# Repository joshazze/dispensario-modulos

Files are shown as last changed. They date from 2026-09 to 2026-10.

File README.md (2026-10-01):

# Dispensário eletrônico · módulos em MDF

Chassi do protótipo do dispensário eletrônico da disciplina de Projeto de Sistemas Embarcados. São dois módulos de MDF cortado a laser, e cada painel é um sanduíche de duas lâminas de 3 mm. Nada aqui foi desenhado à mão: as medidas moram em [`specs/modulos.json`](specs/modulos.json), o [`gerador.py`](gerador.py) desenha, confere e exporta.

A linguagem construtiva (enforca-gato, dedos, camada dupla, gota de parede, pílula) está documentada no repositório irmão, **[dispensario-design-system](https://github.com/joshazze/dispensario-design-system)**.

Componentes comprados (LCD, teclado, parafusos, prensa-cabo), a fonte de cada medida usada no desenho e os arquivos de cada um estão em **[docs/componentes.md](docs/componentes.md)**.

<p align="center">Vista isométrica do armário e do módulo biométrico</p>

## Estado

| módulo | medida externa (L x A x P) | peças | situação |
|---|---|---|---|
| Biométrico, código `B` | 250 x 1000 x 250 mm | 19 | **pronto para a máquina**, em 4 cargas de até 1000 x 1000 mm |
| Armário, código `A` | 1260 x 1500 x 350 mm | 20 | **rascunho**: 12 painéis são maiores que a mesa |

Já cortadas em 03/09/2026: `BP1`, `BP2`, `BP3`, `BSP`, `B3E`, `B5E`, `BTR` e `BTF`. A `BSP` foi cortada antes de ganhar os vãos do LCD e do teclado; eles saem num arquivo à parte, `interface-vaos.dxf`, para cortar na peça que já existe.

Máquina de referência: eCNC L-1210, mesa de 1150 x 1000 mm. Cada carga usa no máximo 1000 mm de largura, folga entre peças incluída, e os 150 mm que sobram ficam de margem.

## Arquivos de corte

```
cortes/
├── biometrico/
│   ├── modulo-biometrico-bloco1.dxf   ← carga 1 da máquina (e .pdf, .svg)
│   ├── modulo-biometrico-bloco2.dxf
│   ├── modulo-biometrico-bloco3.dxf
│   ├── modulo-biometrico-bloco4.dxf
│   ├── modulo-biometrico.dxf          ← as 19 peças numa prancha só
│   └── interface-vaos.dxf             ← só os vãos do LCD e do teclado, sem contorno
└── armario/
    └── modulo-armario.dxf             ← prancha de conferência, ainda não cortável
```

Para a máquina vai o `.dxf`. O `.pdf` tem a mesma prancha em escala 1:1 para conferir na tela ou imprimir, e o `.svg` é o mesmo desenho em vetor.

Todo DXF sai no perfil que o técnico do laboratório usa: AutoCAD 2018 (AC1032), unidade em milímetro, camada `CORTE` na cor 1 (vermelho), contornos em `LWPOLYLINE` e `CIRCLE`, sem moldura da mesa e com o ponto mais baixo à esquerda em (0, 0). Os furos e recortes vêm antes do contorno externo de cada peça: cortado o perímetro, a peça se solta e o furo sairia torto.

### As quatro cargas do biométrico

| carga | área ocupada | peças |
|---|---|---|
| 1 | 1000 x 944 mm | `B1I`, `B1E`, `B2I`, `BPM` |
| 2 | 1000 x 766 mm | `B2E`, `B4I`, `B4E` |
| 3 | 1000 x 1000 mm | `B6I`, `B6E`, `BP1`, `BP2`, `BP3`, `BSP`, `BTR`, `BTF` |
| 4 | 766 x 508 mm | `B3I`, `B3E`, `B5I`, `B5E` |

As tampas `BTR` e `BTF` saem de dentro da janela da frente `B6E`: aquele MDF já estava pago.

<table>
<tr>
<td width="50%">Carga 1 do biométrico<br><sub>Carga 1</sub></td>
<td width="50%">Carga 2 do biométrico<br><sub>Carga 2</sub></td>
</tr>
<tr>
<td>Carga 3 do biométrico<br><sub>Carga 3</sub></td>
<td>Carga 4 do biométrico<br><sub>Carga 4</sub></td>
</tr>
</table>

Na prancha as peças retangulares ficam sempre **deitadas**, com o lado maior na horizontal. Um painel de 250 x 1000 que fica em pé no módulo aparece girado 90° no desenho, e o rasgo que é vertical na montagem aparece horizontal aqui.

## Como ler os códigos

Cada lâmina tem um código de três partes: **módulo**, **face** e **lâmina**. `B6E` é a lâmina externa da frente do biométrico.

| módulo | face | lâmina |
|---|---|---|
| `B` biométrico | `1` fundo (lado da parede) | `I` interna |
| `A` armário | `2` lateral esquerda | `E` externa |
| | `3` piso | |
| | `4` lateral direita | |
| | `5` teto | |
| | `6` frente | |

Peças avulsas levam três letras:

| código | peça | medida | lâminas |
|---|---|---|---|
| `BSP` | sub-painel da interface, atrás da janela da frente | 240 x 560 mm, 8 parafusos, vãos do LCD 1602A e do teclado 4x4 | 1 |
| `BPM` | placa que fecha o vão de manutenção do fundo | 170 x 920 mm, 16 parafusos | 1 |
| `BP1` a `BP3` | prateleiras em U com abas nas laterais | 250 x 236 mm | 1 |
| `BTR`, `ATR` | tampa do passa-fio com furo para prensa-cabo PG16 | ⌀90 mm, furo ⌀22,5 | 1 |
| `BTF`, `ATF` | tampa cega do passa-fio | ⌀90 mm | 1 |
| `AP1` a `AP3` | folhas da porta do armário, em pílula | 1072 x 372 mm | 2 |

### O que cada face do biométrico leva

| face | feições |
|---|---|
| 1 fundo | vão de manutenção 110 x 860, 16 furos da placa `BPM`, 4 gotas de parede, enforca-gato |
| 2 e 4 laterais | passa-fio ⌀50 com 4 furos da tampa, 3 pares de rasgos de prateleira, enforca-gato |
| 3 piso e 5 teto | 4 duplas de enforca-gato, uma virada para cada parede |
| 6 frente | janela da interface 180 x 500, 8 furos do sub-painel `BSP`, enforca-gato |

Cada feição está explicada, com medida e regra, no [design system](https://github.com/joshazze/dispensario-design-system).

## Armário

<p align="center">Peças do armário</p>

A porta são três pílulas deitadas de 1080 x 380 mm na frente, cada uma com a folha própria (`AP1` a `AP3`) 4 mm menor por lado. Nesta figura o painel da frente está girado, por isso as pílulas aparecem em pé. As laterais levam o passa-fio igual ao do biométrico.

O armário ainda não é cortável: os painéis de 1260 x 1500 não entram na mesa de 1150 x 1000, e as folhas da porta, com 1072 mm, passam da carga de 1000 mm. Nada disso fica escondido: cada peça dessas ganha uma carga própria marcada como `FORA DE MEDIDA`.

## Gerar de novo

Requisitos: Python 3.10 ou mais novo, sem biblioteca externa. O PDF usa o Google Chrome ou Chromium; sem ele, o gerador avisa e pula só o PDF (dá para apontar o caminho com `CHROME=...`).

```bash
python3 gerador.py --filtro '^B' --nome biometrico/modulo-biometrico
python3 gerador.py --filtro '^A' --nome armario/modulo-armario
python3 gerador.py --vaos BSP --nome biometrico/interface-vaos
python3 previas.py        # figuras deste README
```

`--vaos CODIGO` exporta só as aberturas marcadas com `componente` naquela peça avulsa, sem o contorno, com a origem no canto de baixo à esquerda.

Para mudar uma medida, edite `specs/modulos.json` e rode o gerador de novo. Ele imprime o tamanho de cada carga, o aproveitamento do material, a tabela de peças contra a mesa e, se houver, cada problema de fabricação encontrado.

`--filtro` é uma expressão regular sobre o código da peça (`'^B6'` pega só a frente do biométrico) e `--nome` escolhe pasta e nome dentro de `cortes/`.

### Testes

```bash
python3 -m pip install -r requirements-dev.txt
python3 -m pytest
```

São 27 testes. Entre outras coisas, eles garantem que:

* cada painel tem duas lâminas de 3 mm e a junta de dedos tem 6 mm de profundidade;
* nenhuma peça invade outra na prancha e toda feição fica dentro da peça, longe da borda;
* a fenda de toda gota de parede aponta para cima e nenhuma gota fica debaixo da placa `BPM`;
* nas quatro paredes do biométrico, o rasgo de enforca-gato fica a pelo menos 9 mm (3x a espessura) de qualquer outra feição;
* a aba da prateleira bate com o rasgo da lateral;
* o vão da porta sai com uma linha de corte só;
* nenhuma carga do biométrico passa de 1000 mm de largura;
* o DXF sai sem moldura, com o canto de baixo à esquerda na origem;
* o arquivo de vãos da interface sai sem o contorno da `BSP`, com os furos em 75 x 31 (LCD) e 60 x 59 (teclado), cada vão centrado nos seus furos;
* a ponte abaixo do piso só é aceita na peça onde a spec declara a exceção.

## Pendências

* **Kerf e espessura são estimativa.** O kerf de 0,18 mm e a espessura de 3,00 mm do MDF ainda não foram medidos, e a compensação de kerf está desligada. Falta cortar um cupom de calibração e medir com paquímetro.
* **Armário não cabe na mesa.** Sai por emenda dos painéis ou por uma altura menor.
* **Frente do armário:** visor, dobradiça e tranca ainda não estão no desenho.
* **Interface do biométrico:** cortar um teste de `interface-vaos.dxf` num retalho com o LCD e o teclado na mão, e só depois o corte oficial. O sensor biométrico ainda não foi escolhido. Detalhe em [docs/componentes.md](docs/componentes.md).
* **Armário:** terminar a modelagem do módulo e dos componentes dele.

## Estrutura

| caminho | o que é |
|---|---|
| `specs/modulos.json` | todas as medidas, em mm |
| `docs/componentes.md` | componentes, fonte de cada medida e arquivos |
| `gerador.py` | desenha faces, feições e peças avulsas, encaixa nas cargas e exporta |
| `previas.py` | figuras do README |
| `laser/` | geometria, escritor de DXF, relatório e registro de material |
| `perfis/` | modelo de DXF do técnico e o perfil extraído dele |
| `materiais.json` | kerf e espessura por material, marcados como `estimado` ou `medido` |
| `third_party/tabbedboxmaker/` | matriz de juntas de dedos das seis faces |
| `tests/` | validação automática |

## Licença

© 2026 Joshua Azze Distel. Código e desenhos sob a [GNU GPL v2](LICENSE), porque o gerador usa o [TabbedBoxMaker](https://github.com/paulh-rnd/TabbedBoxMaker), que é GPL v2 e está preservado em `third_party/tabbedboxmaker/`.

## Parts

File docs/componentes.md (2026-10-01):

# Componentes, fontes e arquivos

Registro de tudo que entra no chassi além do MDF: o componente físico, de onde saiu cada medida usada no desenho e em que arquivo ela mora. Medida sem fonte não entra no `specs/modulos.json`; quando a fonte é fraca (foto, desenho sem cota), isso fica escrito aqui e no campo `fonte` da própria spec.

A linguagem construtiva (enforca-gato, dedos, camada dupla, gota de parede, pílula) está no repositório irmão, [dispensario-design-system](https://github.com/joshazze/dispensario-design-system).

## Interface do módulo biométrico

Os componentes de interface ficam no sub-painel `BSP` (240 x 560 mm, 1 lâmina), que vai atrás da janela de 180 x 500 da frente `B6E`. A regra de montagem é a mesma para todos: **só a parte saltada atravessa a chapa**, e a placa ou base do componente é parafusada por trás, encostada no MDF.

Os dois ficam centrados na largura da `BSP`. O LCD tem o centro dos furos a 480 mm da base da peça e o teclado a 380, então o LCD fica 100 mm acima do teclado.

### LCD 1602A (16 x 2)

| item | valor |
|---|---|
| peça do grupo | módulo 1602A Ver5.5, fundo azul, 16 pinos na borda longa, moldura metálica preta |
| placa | 80 x 36 mm |
| furos da placa | 4 furos em 75 x 31 entre centros |
| vão na chapa | 78 x 26 mm, com lingueta de 10 x 1 mm nas duas pontas curtas, centrado nos furos |
| furos na chapa | ⌀2,7 mm em 75 x 31, para M2 ou M2,5 |
| ponte mais fina | ~1,15 mm entre o vão e cada furo |

O passo dos furos, 75 x 31, é o mesmo nos três datasheets consultados. A moldura não é. Os datasheets dão uma moldura de 70,7 a 71,3 mm de comprimento, mas a foto da peça do grupo mostra a moldura passando cerca de 1 mm além da linha dos furos em cada ponta (uns 76 a 77 mm) e com cerca de 25 mm de altura, centrada nos furos. Valeu a peça: o vão foi dimensionado pela foto, com folga, e não pelos datasheets.

A lingueta existe porque a borda branca do backlight sai uns 1,5 mm de baixo da moldura numa das pontas. Ela foi posta nas duas pontas para o vão servir com a placa montada de qualquer lado.

Na face que encosta na chapa fica a solda dos 16 pinos. Se ela impedir a placa de assentar, uma arruela de cerca de 1 mm em cada parafuso resolve.

**Situação:** a foto não é medida. Antes do corte oficial, o vão passa por um corte de teste (ver Pendências).

### Teclado matricial 4x4 rígido

| item | valor |
|---|---|
| peça do grupo | teclado matricial 4x4 rígido, teclas de plástico, 16 teclas, conector de 10 pinos (anúncio da Smart Componentes) |
| base | 65 x 64 mm, com os 4 furos de fixação nos cantos |
| vão na chapa | 60,5 x 57,5 mm, cantos R4,25, centrado nos furos |
| furos na chapa | ⌀2,4 mm em 60 x 59, para M2 |
| ponte mais fina | ~0,95 mm entre o vão e cada furo |

O vendedor só informa 69 x 65 x 10 mm e "furos de fixação nas extremidades". A geometria vem do Multicomp MCAK1604NBWB, que tem o mesmo corpo (entalhe em cima, aba verde dos pinos embaixo, quatro furos nos cantos): recorte de painel de 60 x 57 com cantos R4, furos de ⌀2,3 em 60 x 59, base de 65 x 64. O Accord AK-1604, de onde o Multicomp deriva, informa o mesmo recorte de 60 x 57.

**Ponte abaixo do piso, aceita.** O próprio fabricante põe os furos colados no recorte, e no MDF de 3 mm sobra cerca de 1 mm entre cada furo e o vão. O piso do projeto é 1,5 mm (metade da espessura). A exceção foi aceita em 01/10/2026 e está declarada na spec da `BSP` (`ponte_aceita_mm` e `ponte_aceita_motivo`). O gerador imprime `EXCECAO DFM BSP` toda vez que roda, e um teste garante que a exceção vale só ali. Se uma ponte trincar, o parafuso ainda aperta a base pelo lado de fora do furo.

### Ainda sem desenho

| componente | situação |
|---|---|
| sensor biométrico | modelo não escolhido |
| monitor touch | desejável, fora do protótipo por ora |

## Fixação e passagem de cabo

| componente | onde | medida usada | fonte |
|---|---|---|---|
| abraçadeira de nylon de 4,8 mm | une as lâminas e as faces (enforca-gato) | rasgo de 6,5 x 2,5 mm | largura da abraçadeira, com folga; ver o design system |
| prensa-cabo PG16 | tampa `BTR` / `ATR` | furo de ⌀22,5 | diâmetro nominal da rosca PG16 |
| parafuso da tampa do passa-fio | tampas ⌀90 sobre o passa-fio ⌀50 | 4 furos em quadrado de 51, piloto ⌀2,5 na parede e passante ⌀3,2 na tampa | M3 |
| parafuso do sub-painel e da placa de manutenção | `BSP` e `BPM` | piloto ⌀2,5 na face, passante ⌀3,2 na peça | M3 |
| parafuso de parede | fundo `B1` | gota com cabeça ⌀12, haste ⌀6,5, fenda de 10 mm para cima | ver o design system |

## Fontes

| fonte | o que deu | link |
|---|---|---|
| Tinsharp TC1602A-01T, p. 4 | furos 75 x 31, moldura 71,3 x 26,8 | [PDF (Adafruit)](https://cdn-shop.adafruit.com/datasheets/TC1602A-01T.pdf) |
| EONE 1602A-1 (Elecrow), p. 12 | furos 75,4 x 31,4 ⌀2,8, moldura 70,7 x 23,8, altura 7,0 | [PDF](https://www.elecrow.com/download/LCD1602.pdf) |
| HJ1602A, p. 2 | furos 75 x 31 ⌀2,5, moldura 70,8 x 23,8 | [PDF (Northwestern)](https://hades.mech.northwestern.edu/images/f/f7/LCD16x2_HJ1602A.pdf) |
| Waveshare LCD1602, p. 18 | placa 80 x 36, furos 75 x 31 | [PDF](https://www.waveshare.com/datasheet/LCD_en_PDF/LCD1602.pdf) |
| foto do LCD do grupo | moldura ~76-77 x ~25, centrada; lingueta do backlight | foto tirada em 01/10/2026, não publicada |
| Multicomp MCAK1604NBWB, p. 2 | recorte 60 x 57 R4, furos ⌀2,3 em 60 x 59, base 65 x 64 | [PDF (Farnell)](https://www.farnell.com/datasheets/1662717.pdf) |
| Accord AK-1604 | recorte de painel 60 x 57, base 65 x 64 | [página do produto (TME)](https://www.tme.eu/en/details/kb1604-pnb/plastic-keypads/accord/ak-1604-n-bbw/) |
| Smart Componentes | teclado 69 x 65 x 10, conector de 10 pinos | [loja](https://www.smartcomponentes.com/modulo-teclado-matricial-16-karet-teclas-alfanum-rico-4x4-arduino) |
| TabbedBoxMaker | matriz de juntas de dedos das seis faces | [GitHub](https://github.com/paulh-rnd/TabbedBoxMaker) |
| técnico do laboratório | perfil do DXF (AC1032, camada `CORTE`) | `perfis/` |

## Arquivos

| arquivo | o que é |
|---|---|
| `cortes/biometrico/interface-vaos.dxf` | **só os vãos e furos do LCD e do teclado**, sem o contorno da `BSP`, para cortar na peça que já foi cortada, alinhando à mão na mesa |
| `cortes/biometrico/interface-vaos.pdf` | o mesmo em escala 1:1, com 5 mm de margem: imprimir em 100% e pôr os componentes de cara para baixo em cima confere tudo sem paquímetro |
| `cortes/biometrico/modulo-biometrico-bloco3.dxf` | carga 3, que tem a `BSP` inteira já com os vãos |
| `specs/modulos.json` | peça `BSP`, campo `aberturas`: cada vão com `componente` e `fonte` |

```bash
python3 gerador.py --vaos BSP --nome biometrico/interface-vaos
```

## Pendências

1. **Corte de teste.** Cortar `interface-vaos.dxf` num retalho, encaixar o LCD e o teclado de verdade e conferir os vãos, os furos e a solda dos pinos.
2. **Corte oficial.** Só depois do teste: os vãos na `BSP` já cortada, ou a `BSP` nova da carga 3.
3. **Medida da moldura do LCD.** Se o teste mostrar folga demais ou de menos, trocar os pontos do vão na spec pela medida de paquímetro.

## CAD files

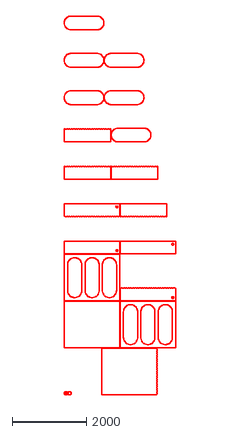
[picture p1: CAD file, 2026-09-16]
cortes/armario/modulo-armario.dxf
3008.0 x 10224.0

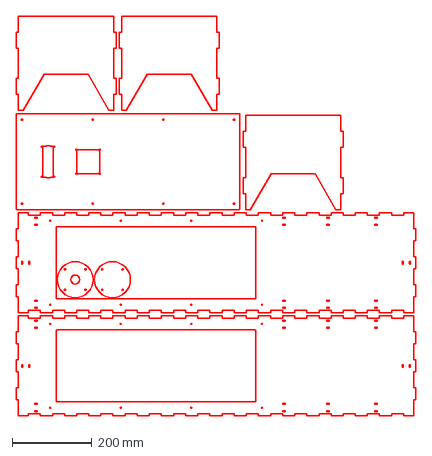
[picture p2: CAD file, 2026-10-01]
cortes/biometrico/modulo-biometrico-bloco3.dxf
1000.0 x 1000.0 mm

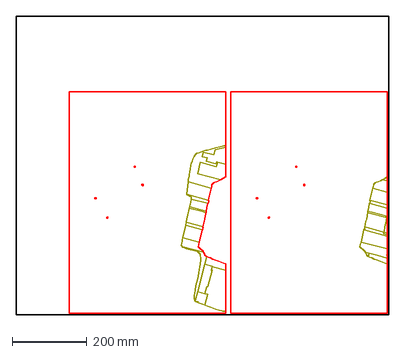
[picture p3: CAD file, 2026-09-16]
perfis/chapa-tecnico.dxf
1000.0 x 800.0 mm

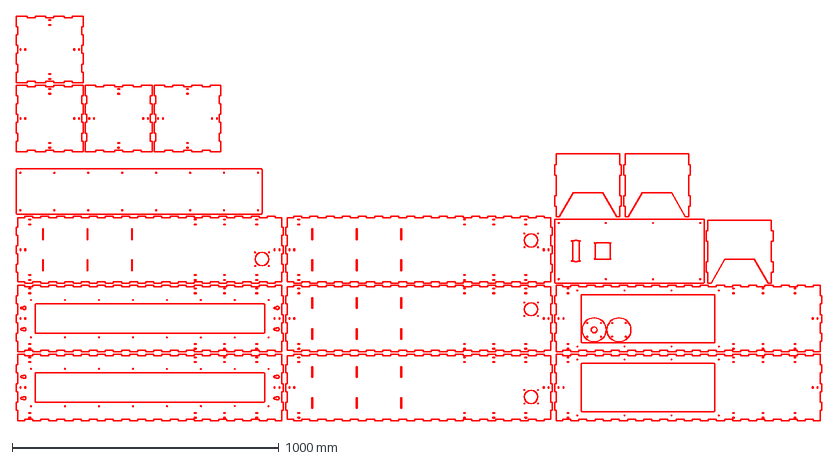
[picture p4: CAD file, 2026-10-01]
cortes/biometrico/modulo-biometrico.dxf
3016.0 x 1516.0 mm

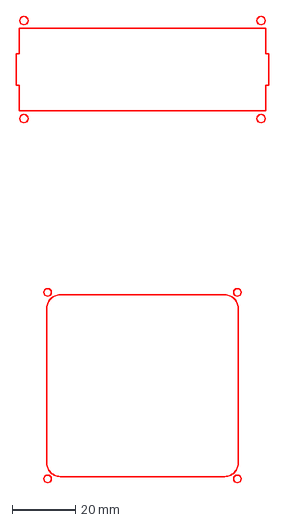
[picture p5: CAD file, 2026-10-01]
cortes/biometrico/interface-vaos.dxf
80.0 x 147.5 mm

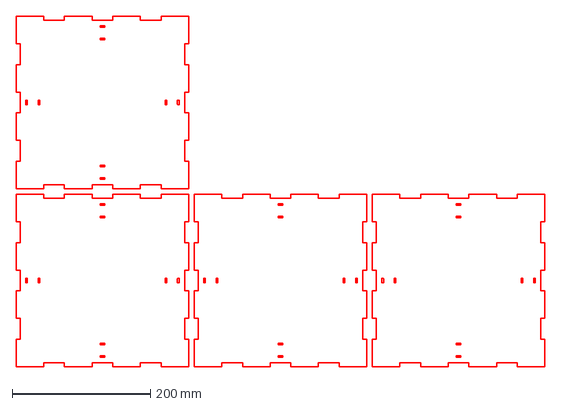
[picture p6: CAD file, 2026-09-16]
cortes/biometrico/modulo-biometrico-bloco4.dxf
766.0 x 508.0 mm

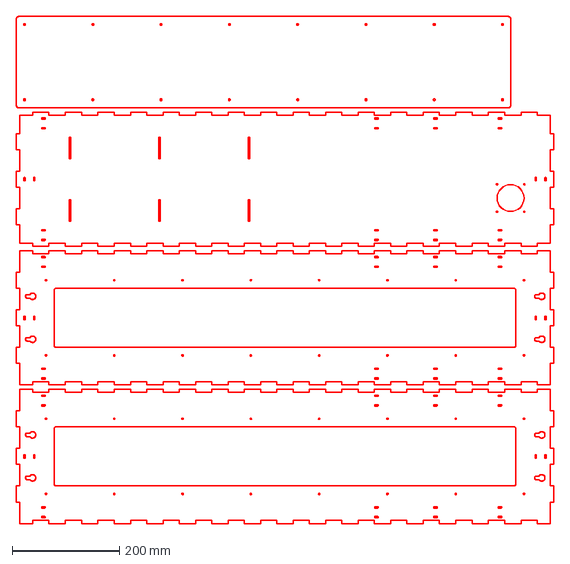
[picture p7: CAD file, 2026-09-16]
cortes/biometrico/modulo-biometrico-bloco1.dxf
1000.0 x 944.0 mm

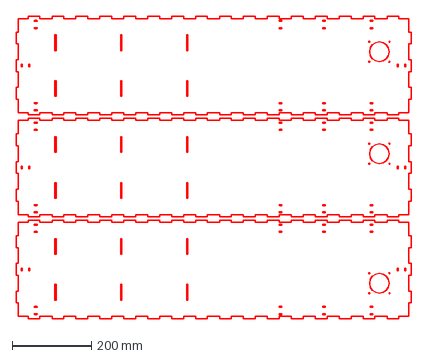
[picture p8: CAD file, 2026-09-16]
cortes/biometrico/modulo-biometrico-bloco2.dxf
1000.0 x 766.0 mm

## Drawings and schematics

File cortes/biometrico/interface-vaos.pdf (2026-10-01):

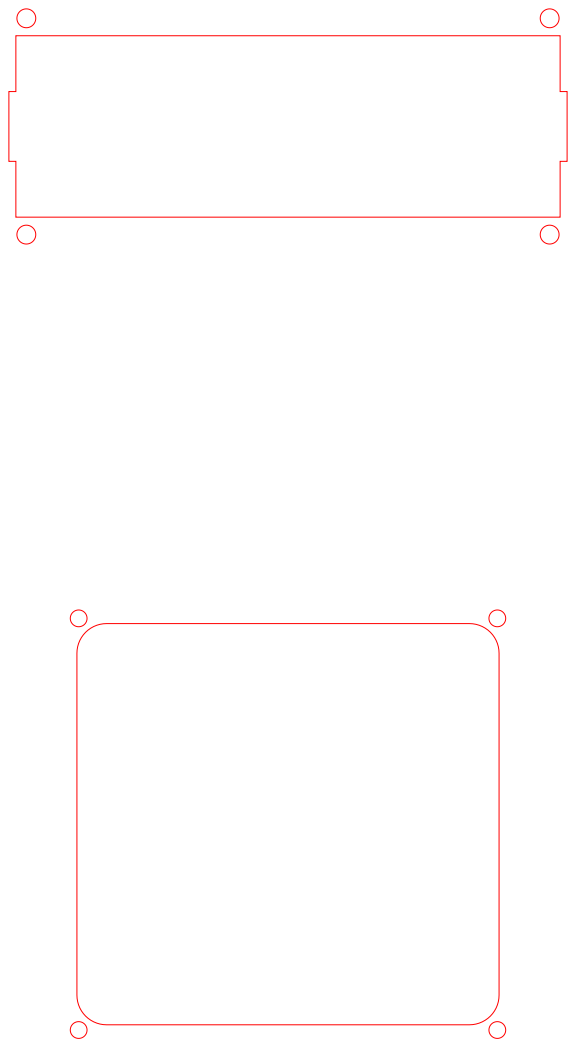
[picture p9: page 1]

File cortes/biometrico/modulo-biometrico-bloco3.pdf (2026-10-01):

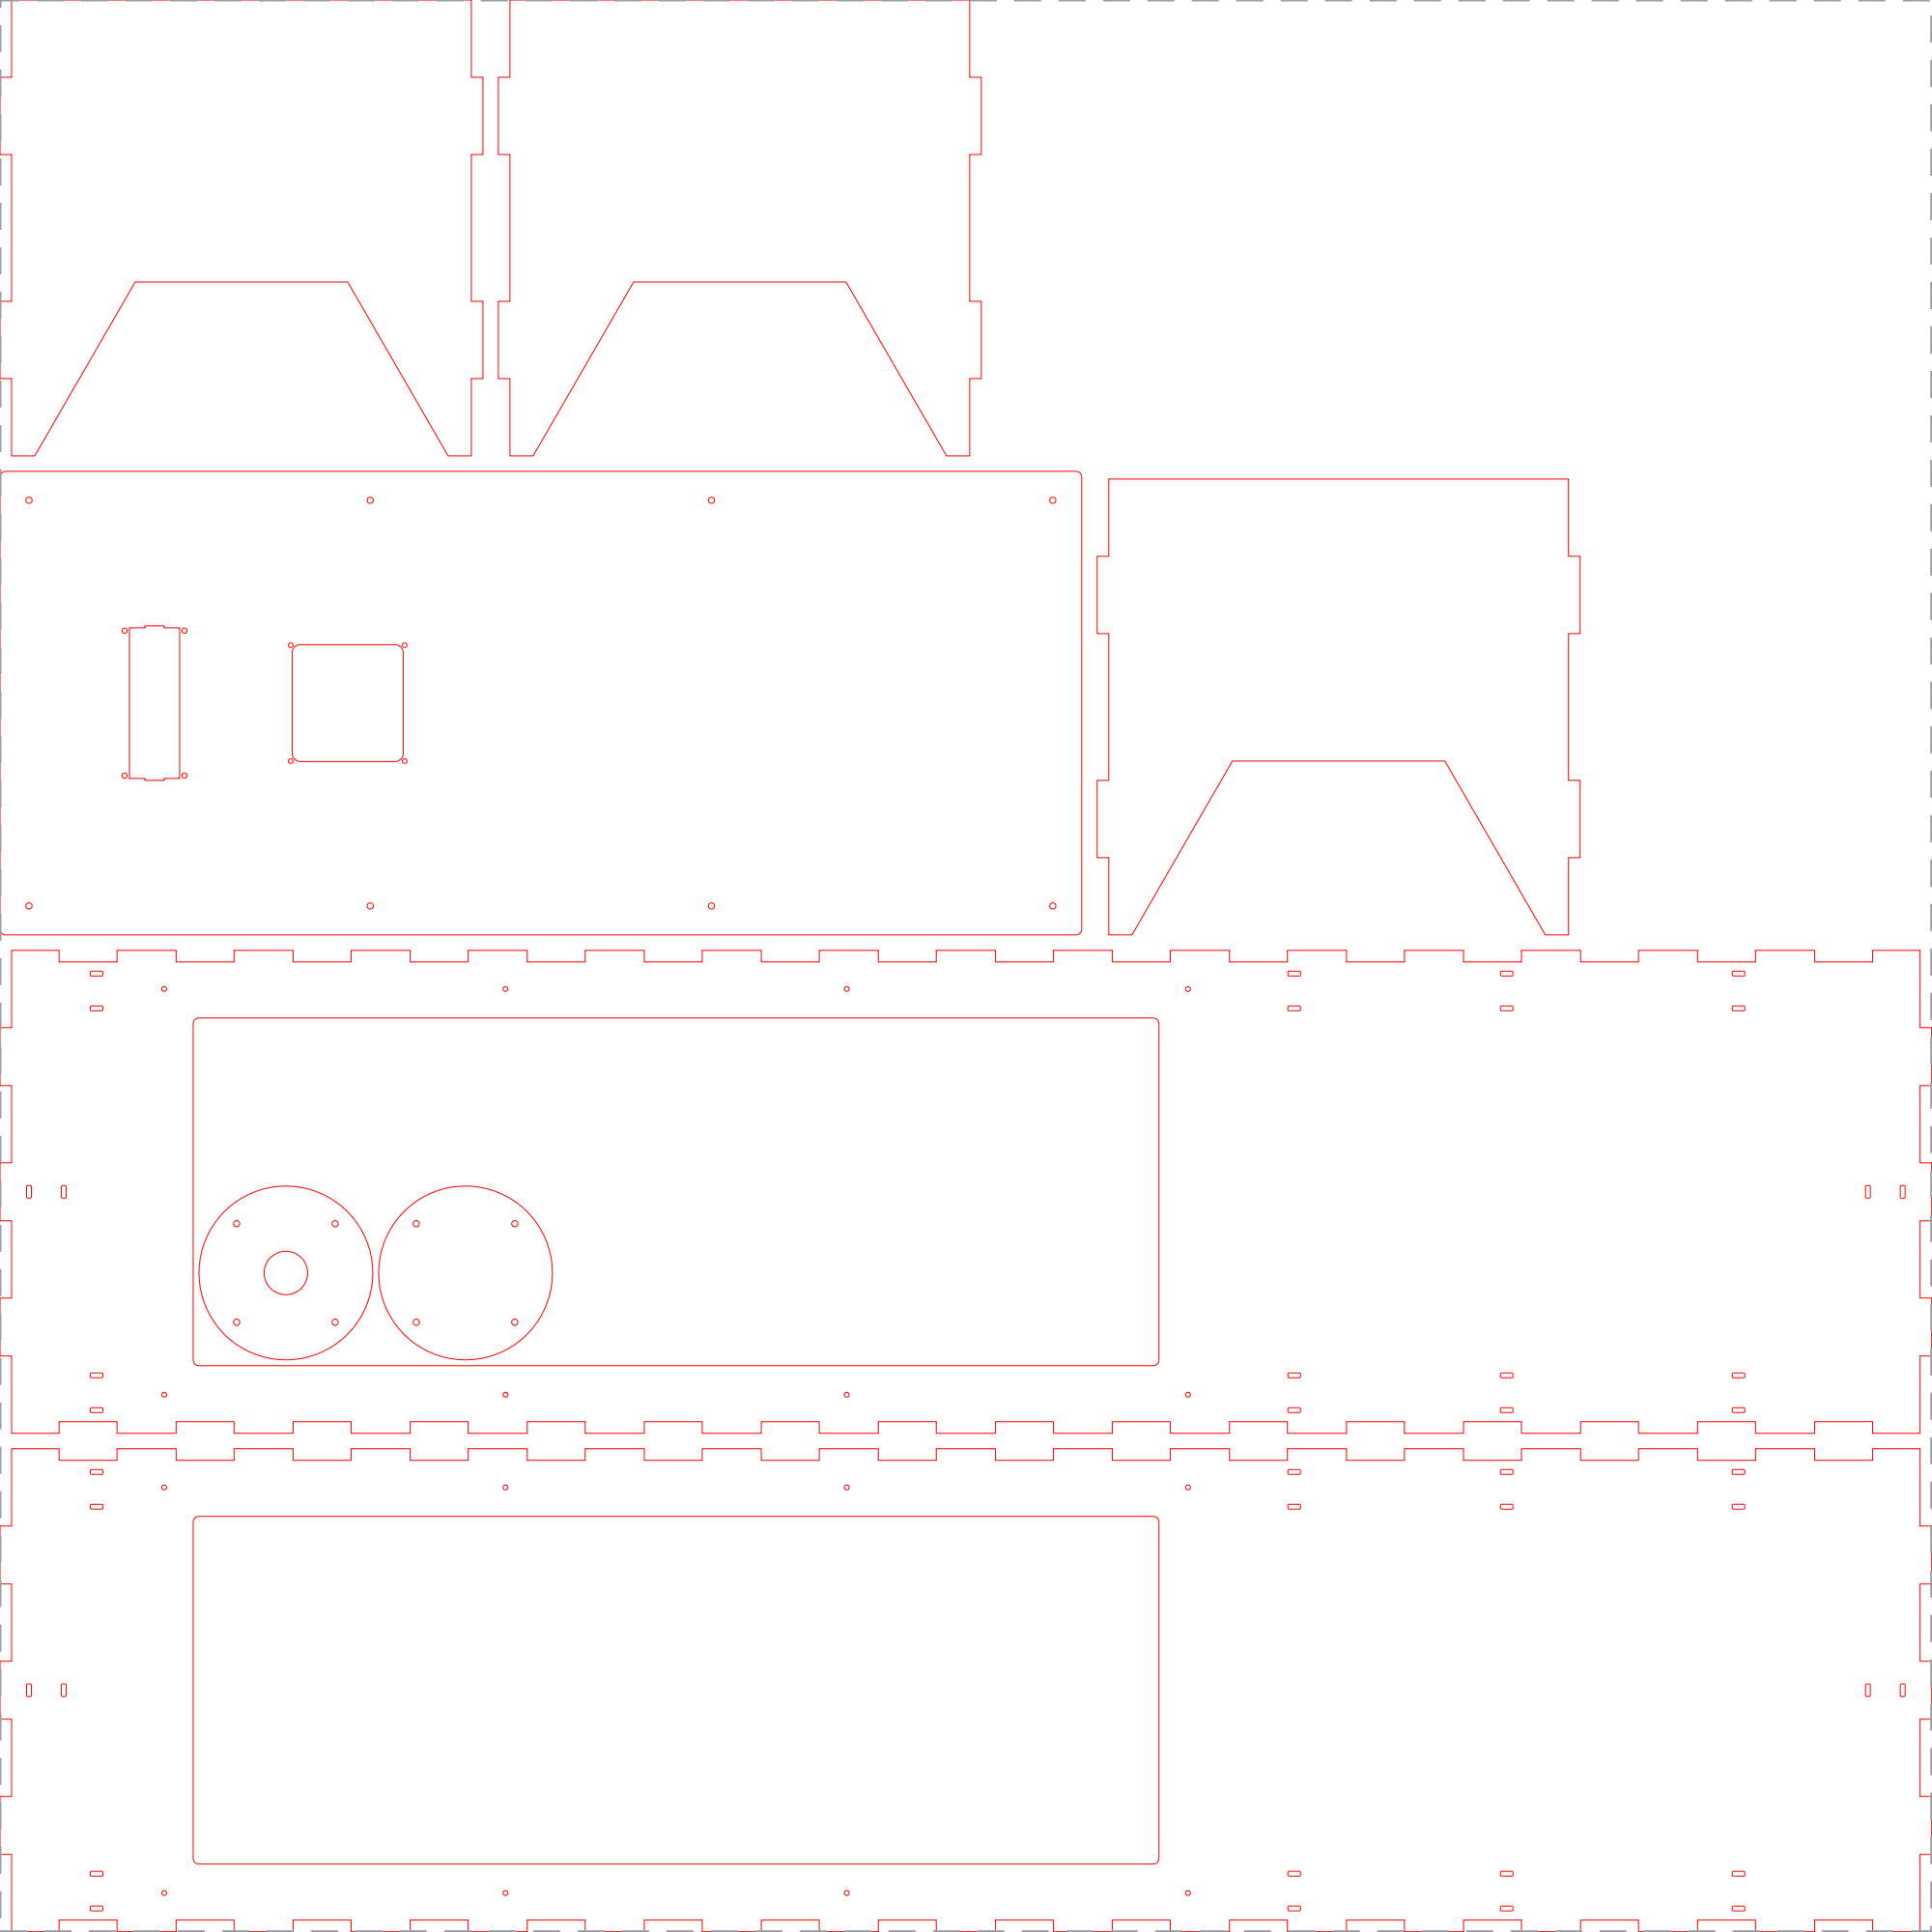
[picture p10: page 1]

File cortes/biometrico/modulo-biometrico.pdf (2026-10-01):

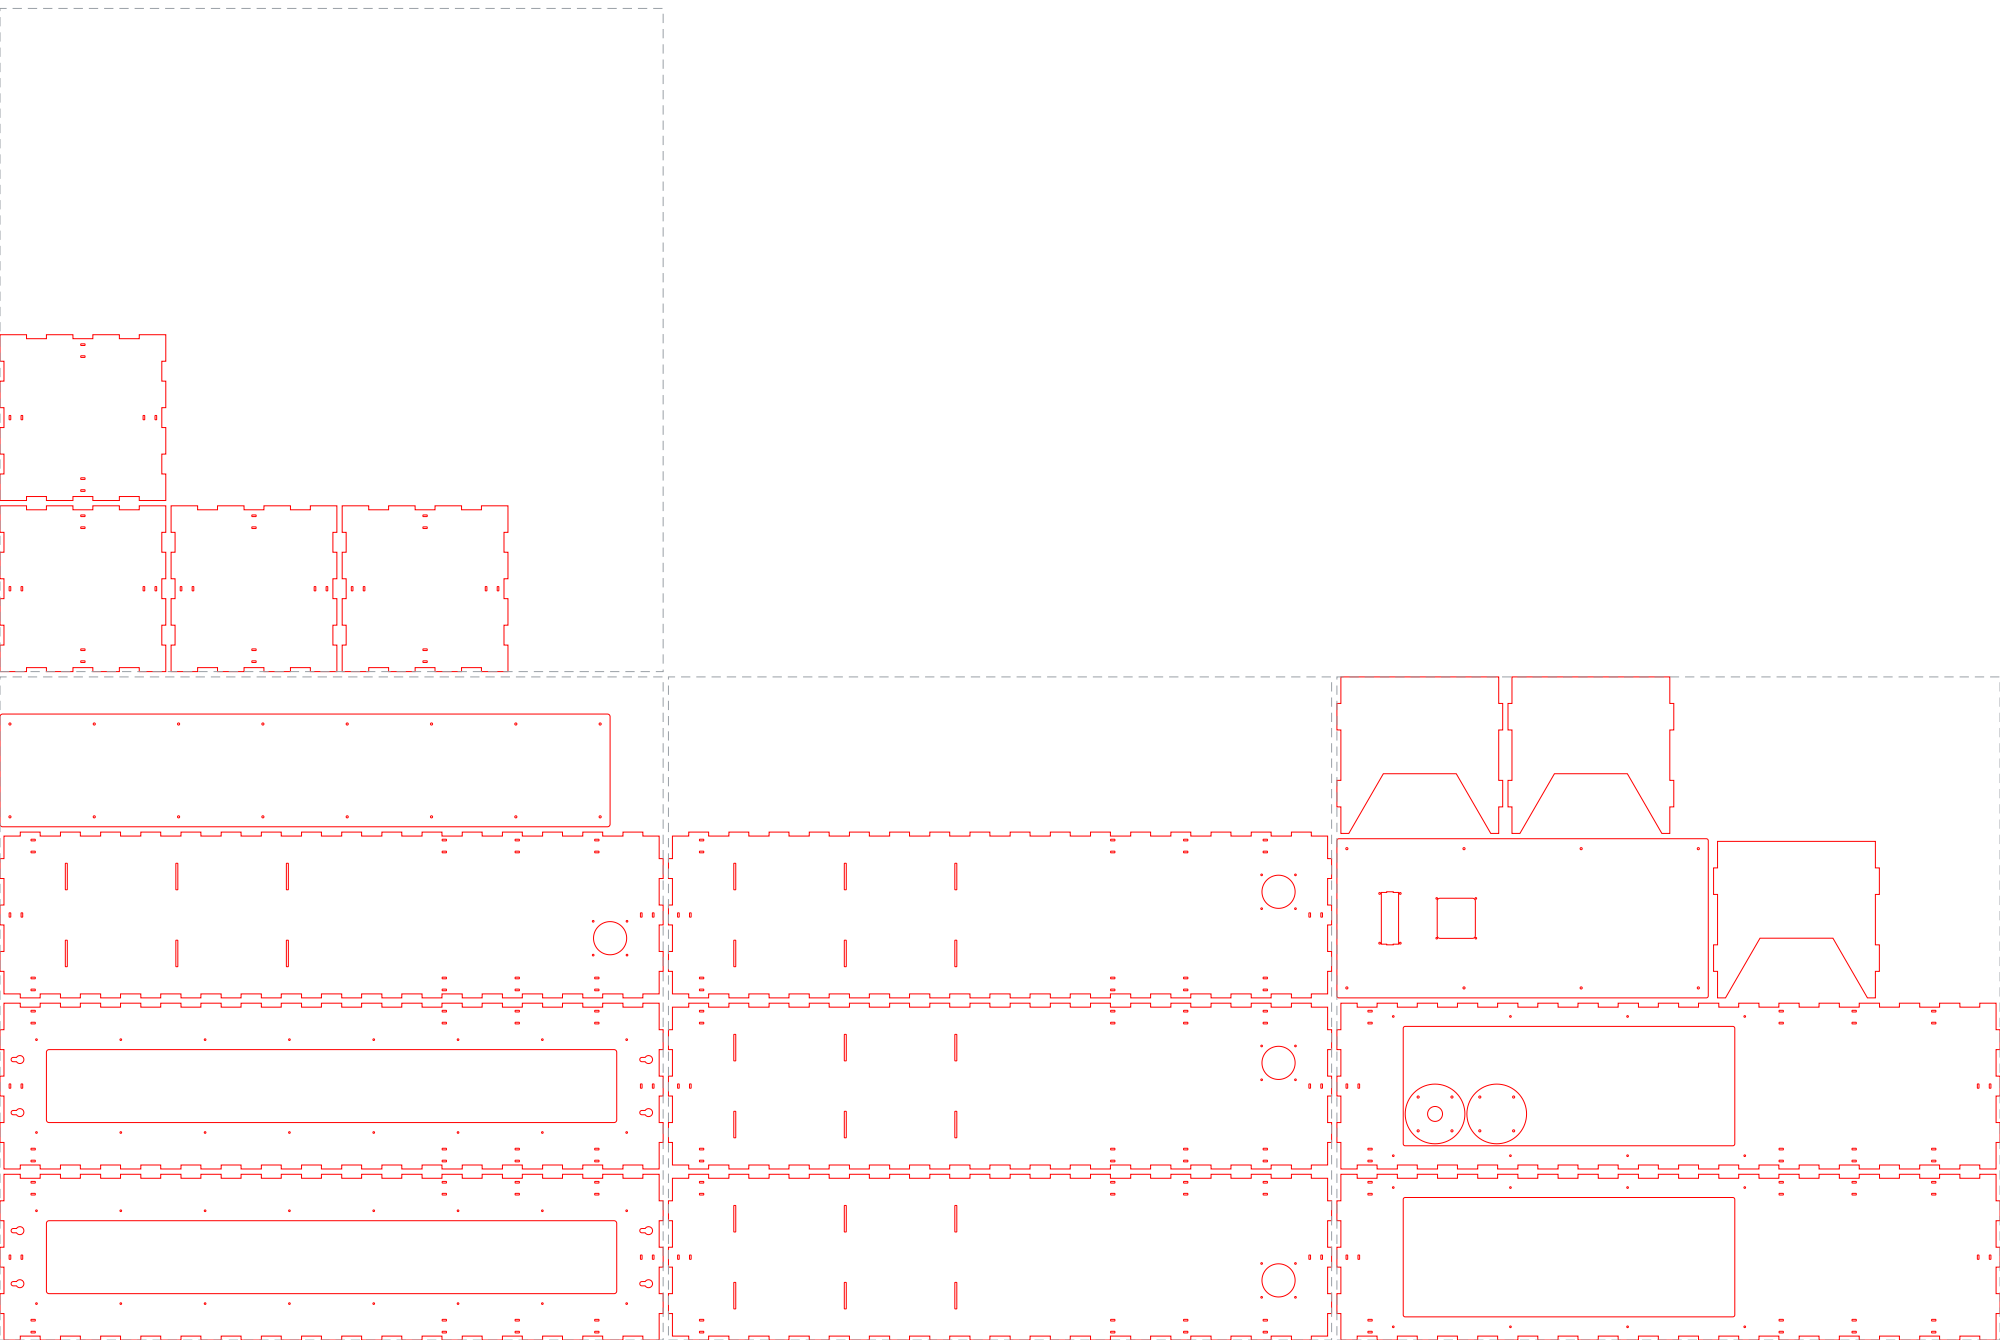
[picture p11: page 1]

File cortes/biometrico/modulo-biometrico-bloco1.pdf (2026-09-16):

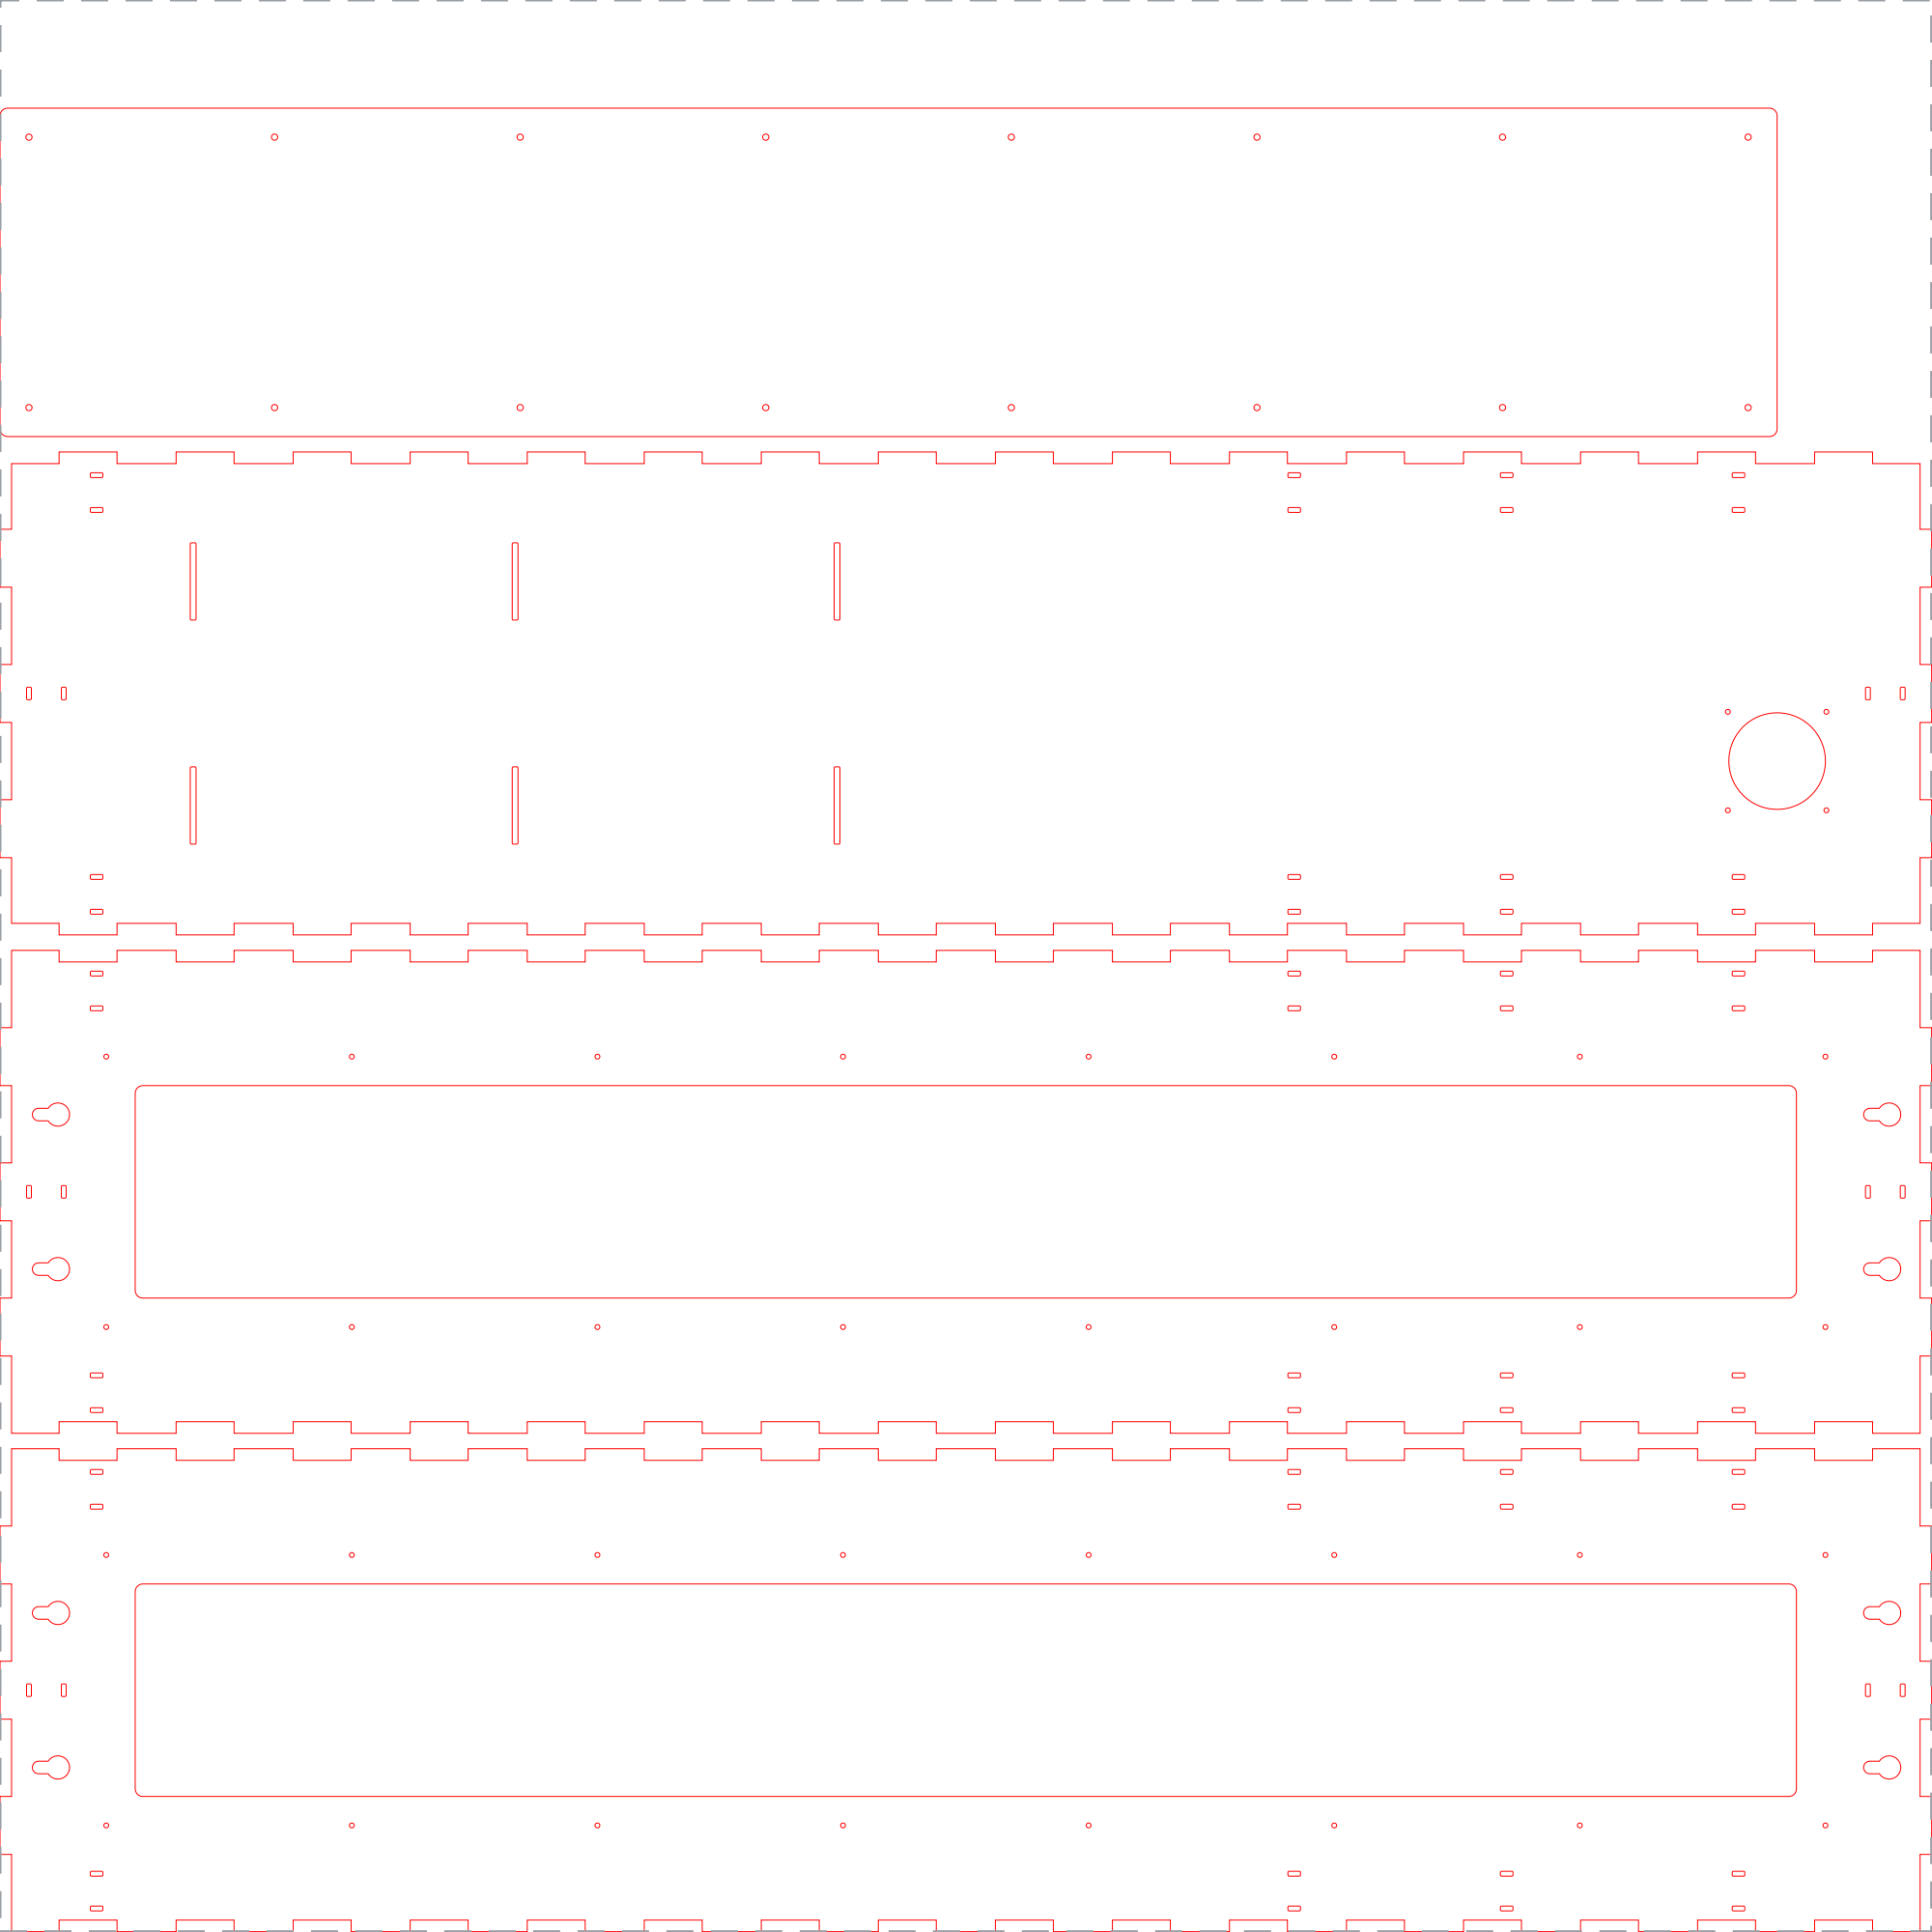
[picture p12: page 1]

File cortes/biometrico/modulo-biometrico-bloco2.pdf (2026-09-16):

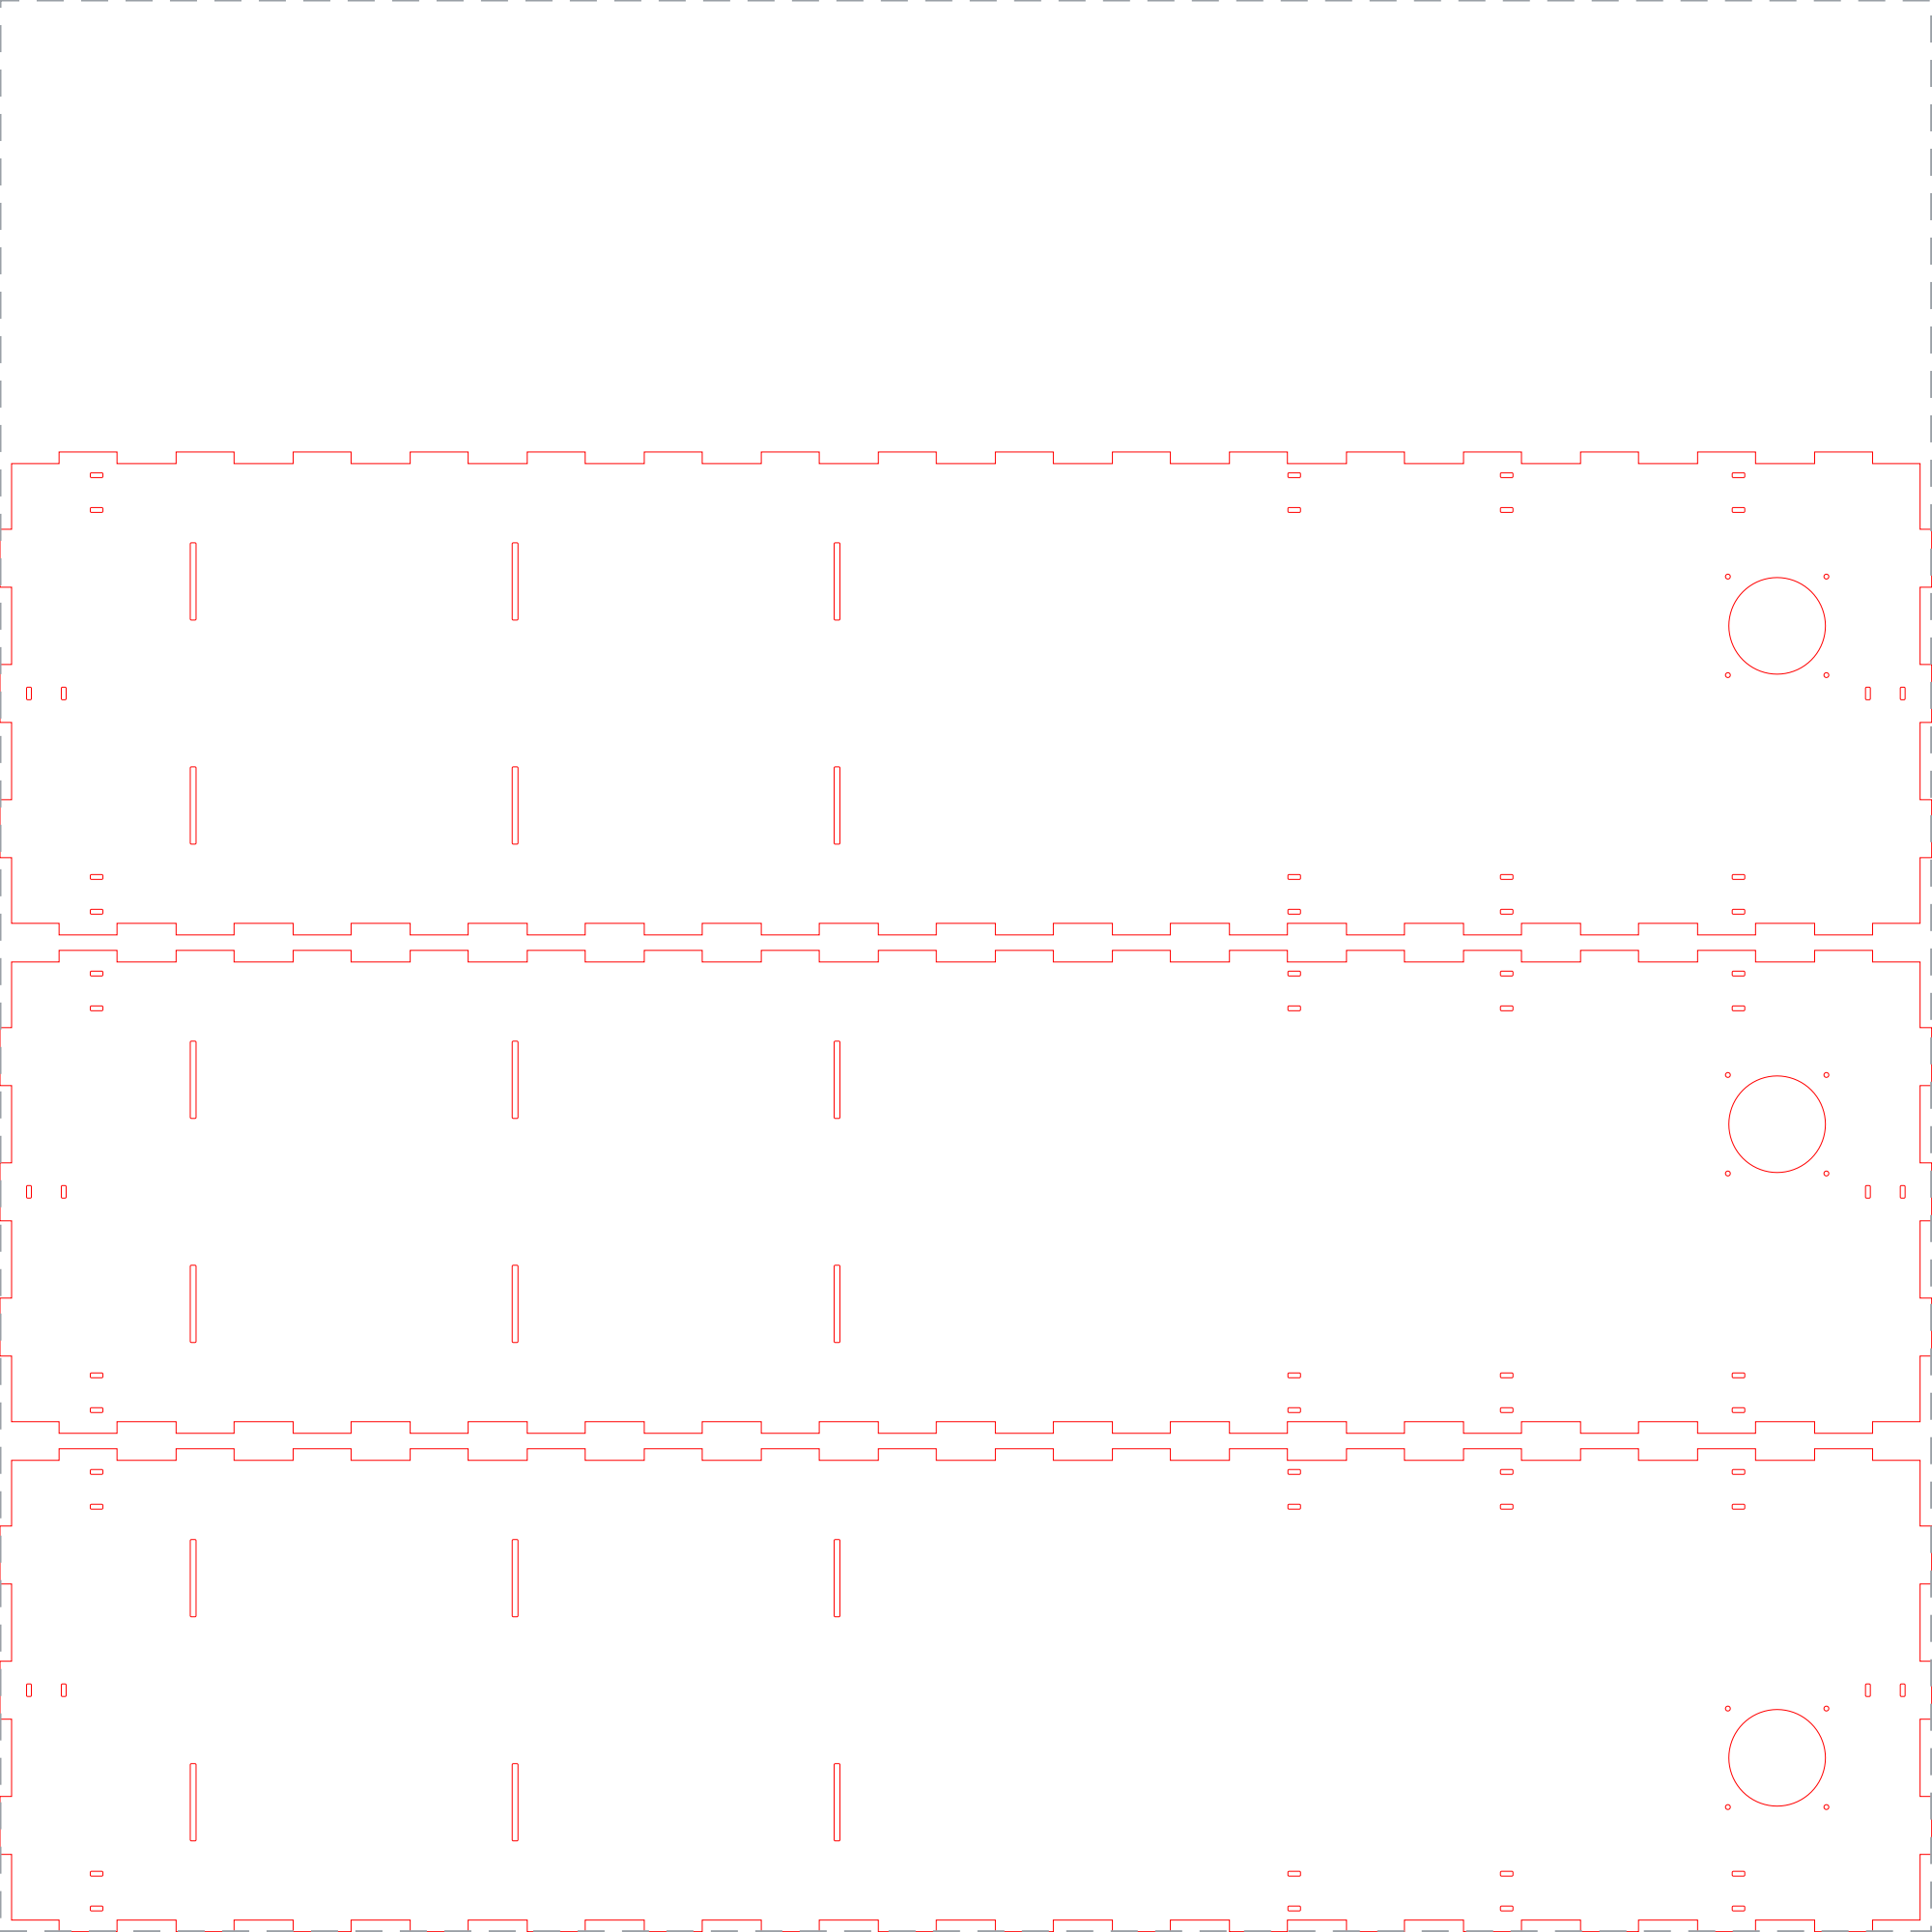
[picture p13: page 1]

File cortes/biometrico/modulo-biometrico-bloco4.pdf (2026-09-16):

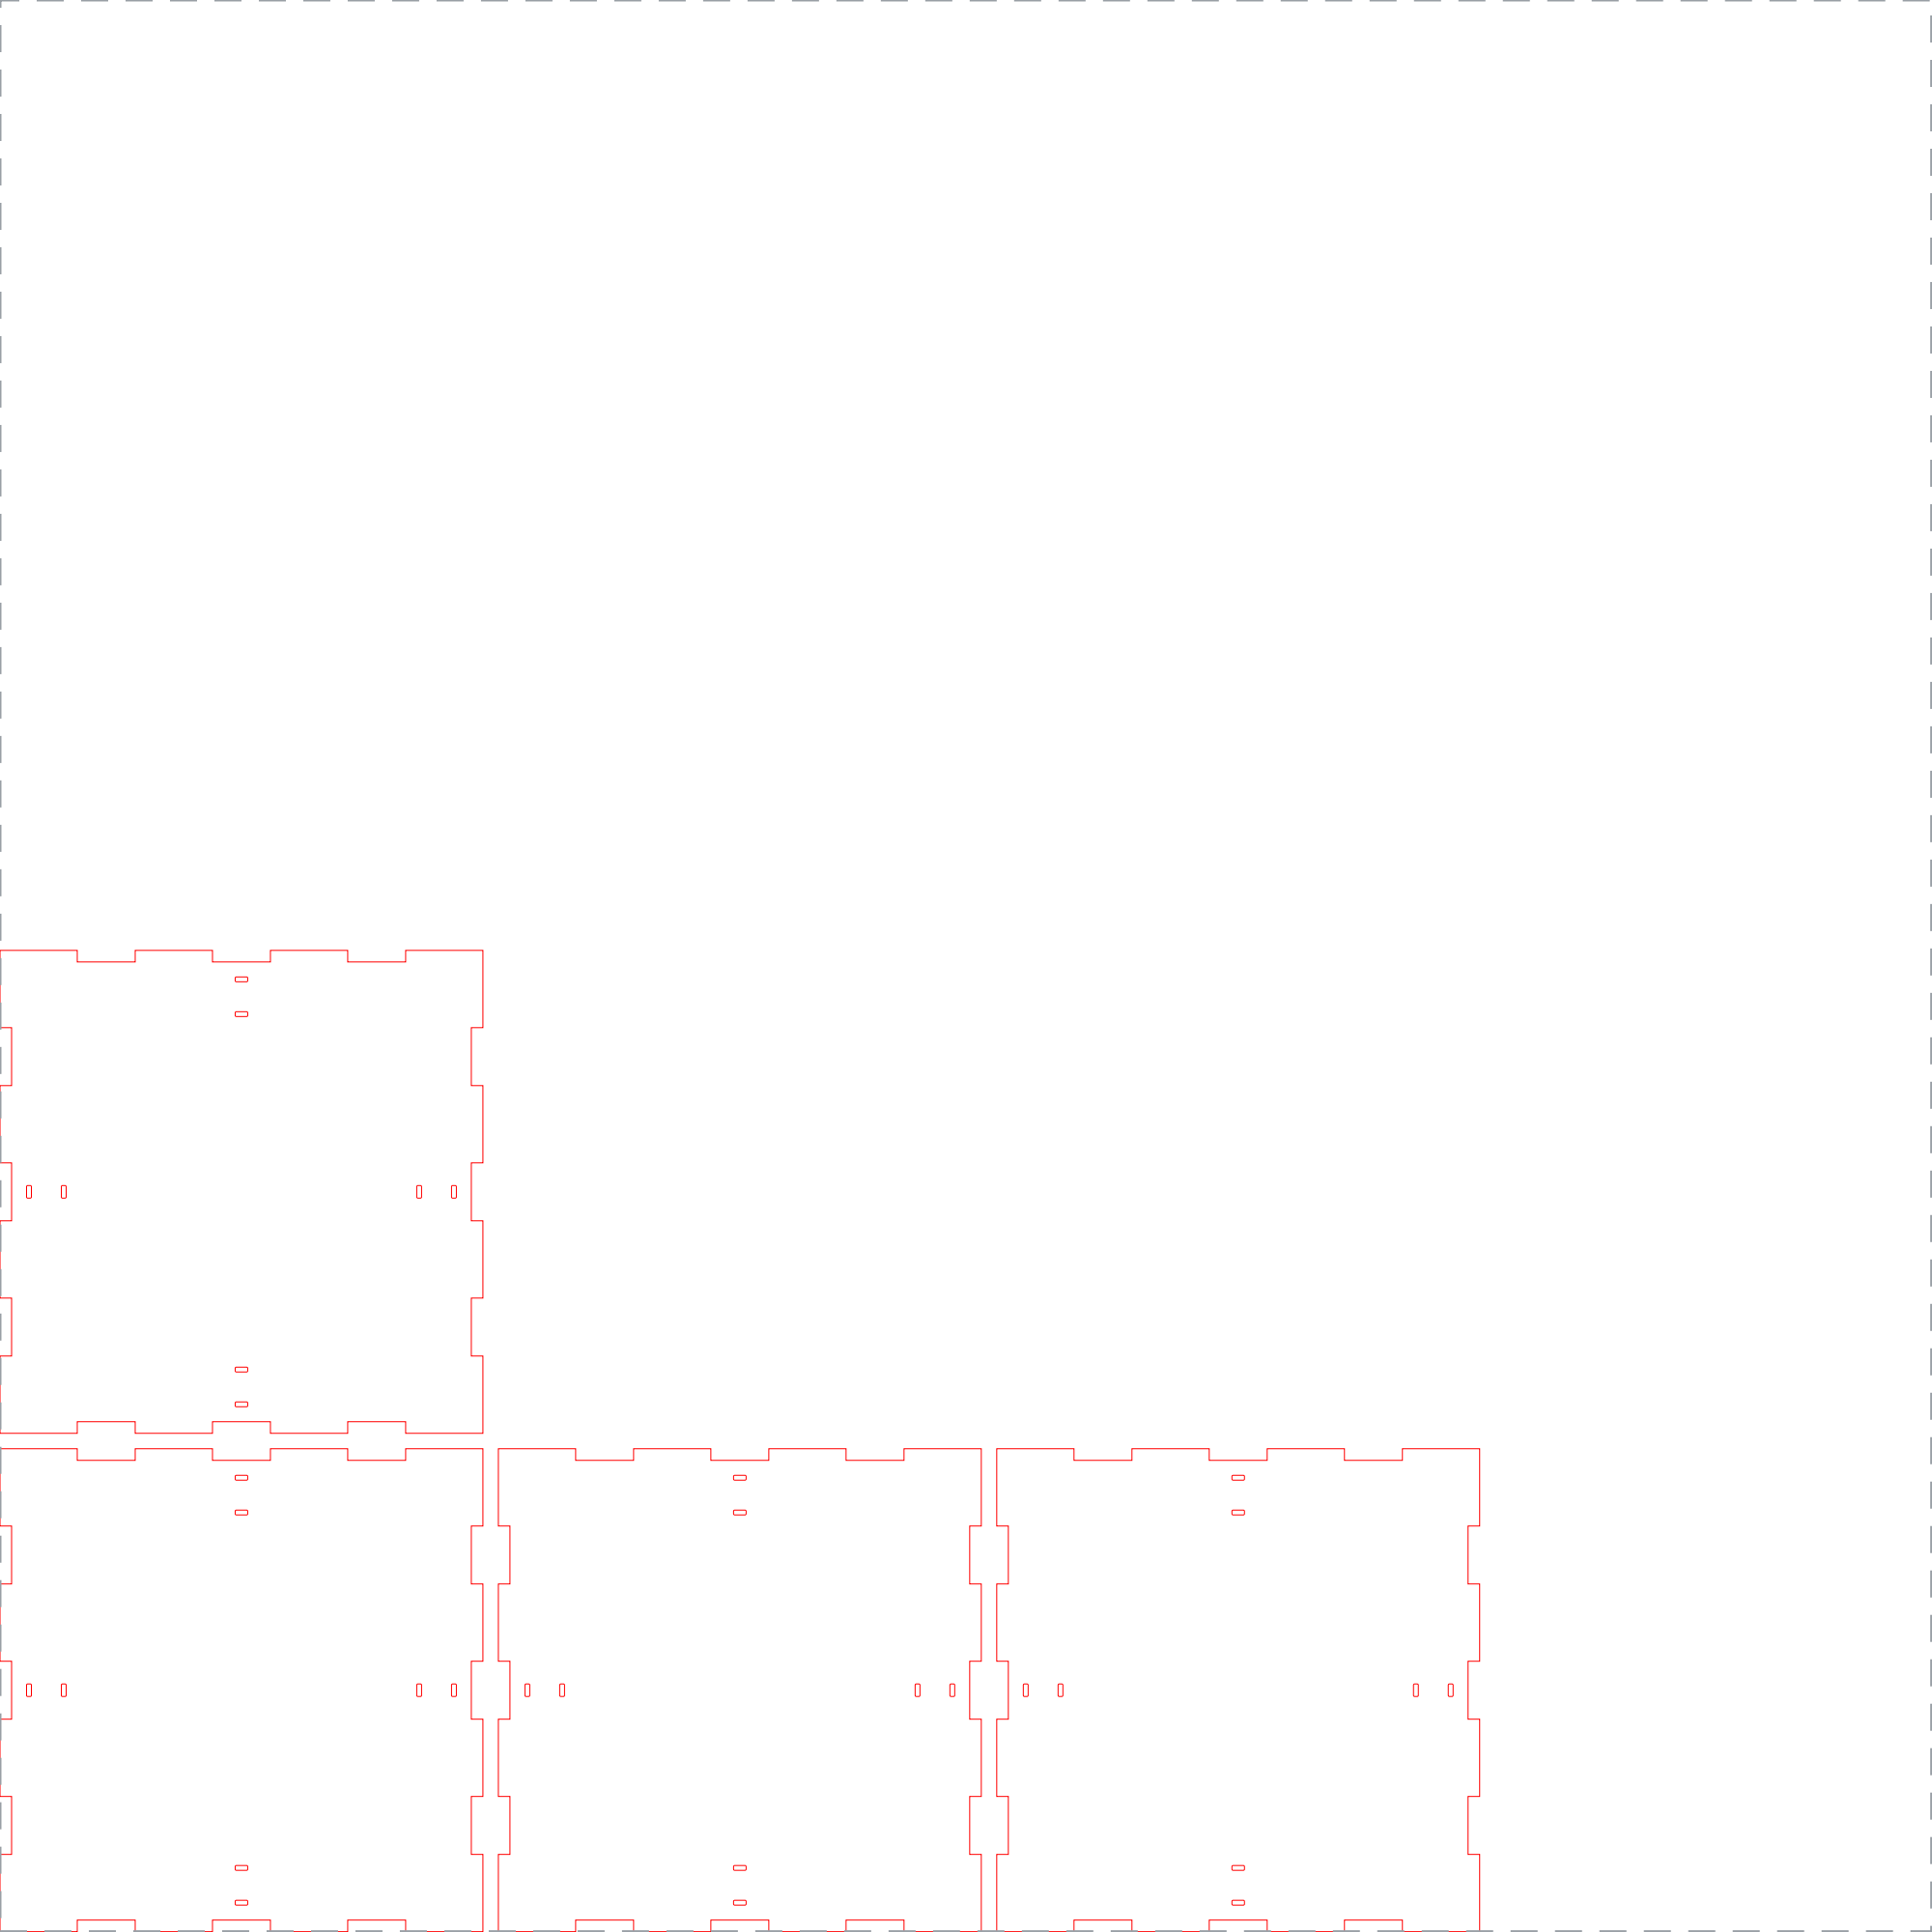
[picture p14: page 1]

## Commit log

2026-09-16 feat: publica chassi do dispensario com gerador e arquivos de corte
    [chapa-tecnico.dxf, modulo-armario.dxf, modulo-biometrico-bloco1.dxf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]
2026-10-01 feat: exporta so os vaos de componente com --vaos
2026-10-01 feat: adiciona vaos do LCD 1602A e do teclado 4x4 na BSP
    [interface-vaos.dxf, modulo-biometrico-bloco3.dxf, modulo-biometrico.dxf]
2026-10-01 test: cobre vaos da interface e excecao de ponte
2026-10-01 docs: aponta README para componentes e design system
2026-11-09 docs: flyback diode installed on the lock
2026-11-09 docs: bench state of 06/11, RFID reader, ID+password login and new LED map
